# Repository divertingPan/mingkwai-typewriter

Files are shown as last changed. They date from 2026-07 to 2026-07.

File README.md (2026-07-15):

# Chinese Mingkwai Typewriter/明快打字机（中文打字机）

[][cc-by-nc]

本项目使用CC BY-NC 4.0进行许可。This work is licensed under a
[Creative Commons Attribution-NonCommercial 4.0 International License][cc-by-nc].[][cc-by-nc]

[cc-by-nc]: https://creativecommons.org/licenses/by-nc/4.0/
[cc-by-nc-image]: https://licensebuttons.net/l/by-nc/4.0/88x31.png
[cc-by-nc-shield]: https://img.shields.io/badge/License-CC%20BY--NC%204.0-lightgrey.svg

这是一个开源项目，欢迎DIYer在此基础上转载/改进/魔改，但请标注来源。禁止盗用、未授权的商用。

## 1. 背景

这是一个我的个人项目，我试图用现代科技来低成本的复现明快打字机，因此不拘泥于纯机械的执念，我的目标是先快速将他运行。

另外，低成本的实现也能帮助更多人自己做或者研究这个东西。

---

## 2. 文件详情

### 字表与字体

所有文件的基础来自于网站[https://mingkwai.atelier-anchor.com/](https://mingkwai.atelier-anchor.com/)

但此网站目前（截至2026年7月3日）暂时更新不可见。

- 项目中展示的字模图样、编码示意图、字体设计等，其原版权归属于原设计团队，本项目仅用于验证机械结构寻址和动作的测试展示，实物仅用于个人研究，绝不用于任何商业用途。

### 带v0.x.x版本号的文件夹

齿轮组与字轴滚筒的联动设计。目前仅有用来模拟运动测试用的最基本模型。后续需要完善装配细节，以及与纸打字的部分的联动。

---

## 3. 成本记录

| 材料\工艺 | 价格 (￥) |
| --- | --- |
| Arduino mega2560（后期开发尽可能兼容uno以再省点成本） | ≈60（祖国版） |
| USB Host Shield* | 19.2 |
| USB有线薄膜键盘 | 9.9 |
| 键盘轴和键帽 | |
| 柔性树脂印版 | 约100一张（A4幅面） |
| 电磁离合器 | |
| 42步进电机（长23） | |
| 闭环驱动 | （可能没必要，且贵） |
| 同步带/轮 | |
| 齿轮通用件 | |
| 3D打印部件耗材+工费（倘若你没有3D打印机） | |
| 治具成本 | |
| 所需工具 | |
| Todo | |

*USB Host Shield的库文件：[felis/USB_Host_Shield_2.0: Revision 2.0 of USB Host Library for Arduino.](https://github.com/felis/USB_Host_Shield_2.0) 

---

## 4. 进度

### （update 20260711）**结构测试_v0.3.1**:

鉴于同步带计算传动比简单很多，因此着重设计了B-roll的结构，使用了多级皮带轮，需要实际做一下，测试精度和稳定性，曾想过把预览轴用屏幕取代，但是感觉会使原机械风味丧失大半，所以还是保留。

【A-roll：最大的转盘，B-roll：二级转盘，C-roll：八面轴，view-roll：预览轴】

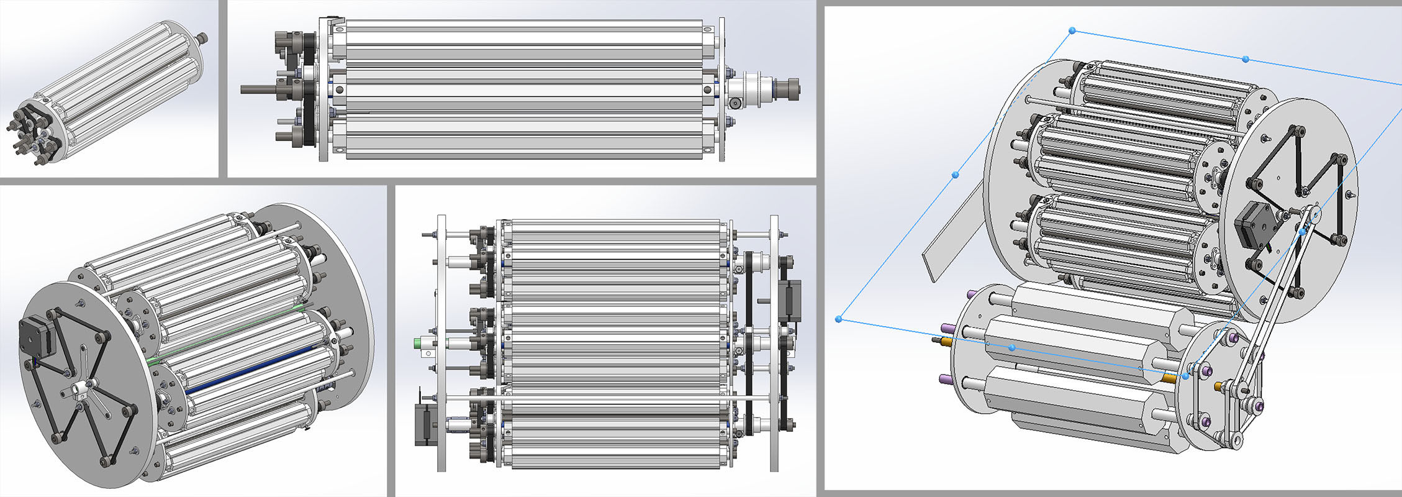
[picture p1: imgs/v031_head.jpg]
v031 preview


打样了印版，对比测试了两种厚度的柔性树脂印版，肉眼观察树脂印版精度效果极佳，但风险是时间久会变硬，对于盖章的影响目前未知。

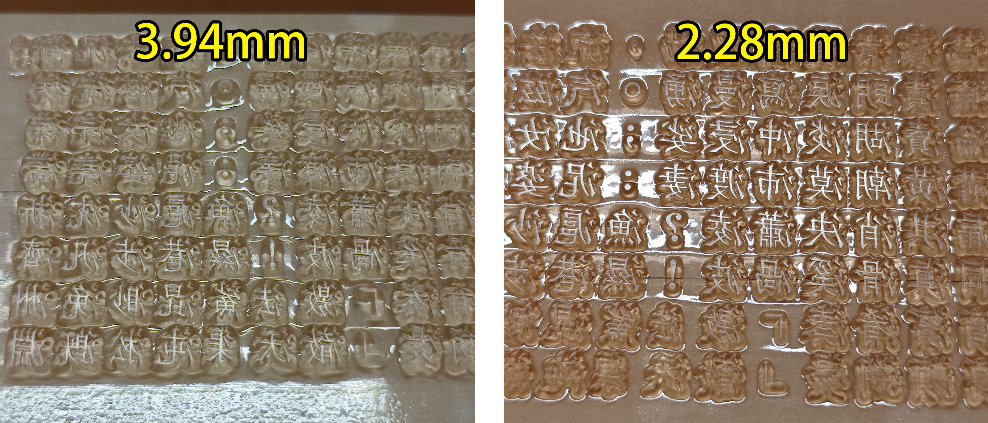
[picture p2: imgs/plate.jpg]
sample of the plate


下面展示的是使用印版沾取7021印油盖印的效果，左侧是轻轻施压，右侧是重压，（靠左的文字是薄印版，靠右的字是厚印版，不特别大力压的话，实际效果差别不大，可以哪个便宜做哪个）可以看出柔性印版对压力的要求没有那么高，在指定字上沾墨，轻轻压向纸面即可。
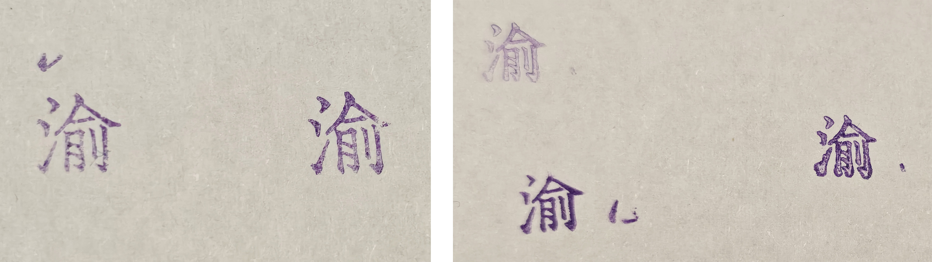
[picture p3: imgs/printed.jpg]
testing the characters


激光雕刻的胶皮不如柔性印版的效果好，盖印时我试了几次都没能完美盖出清晰的字迹。且二者加工成本接近，但是如果提升雕刻精度则会提升工费，且提升效果未知，整体性价比个人认为柔性印版最佳

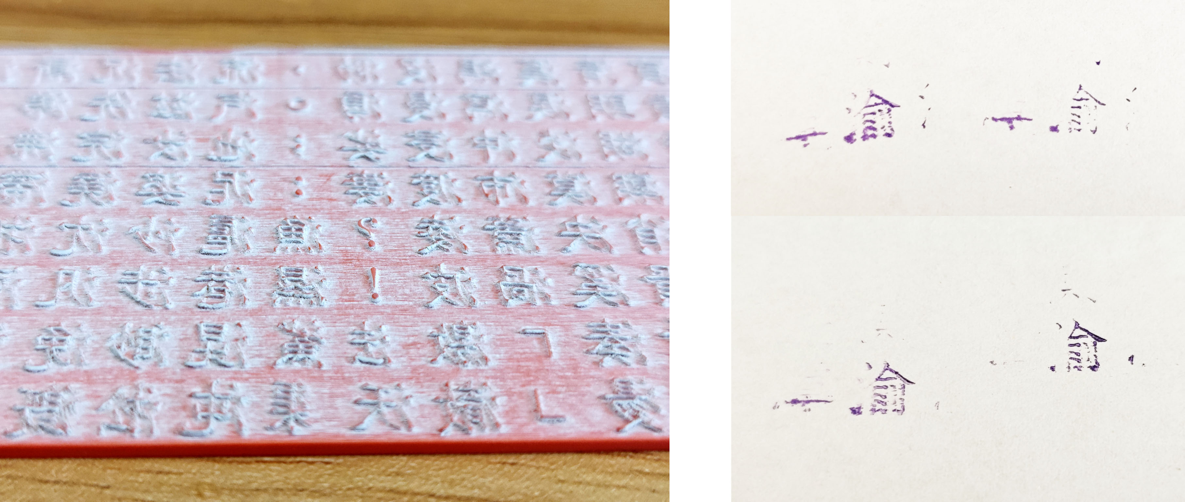
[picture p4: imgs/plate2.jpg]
rubber plate test


### （update 20260703）**结构测试_v0.3.0**:

重构了转轴部分的转盘传动，使用同步带驱动，大幅简化了运动和构造。v0.2.2完全不合理，直接废弃不用看了。

之后的版本需要将设计重心放在电机与轴的配合，代码，如何将字打在纸上（可能会参考回墨戳的设计，鉴于我想要通过橡皮印章方法刻字）

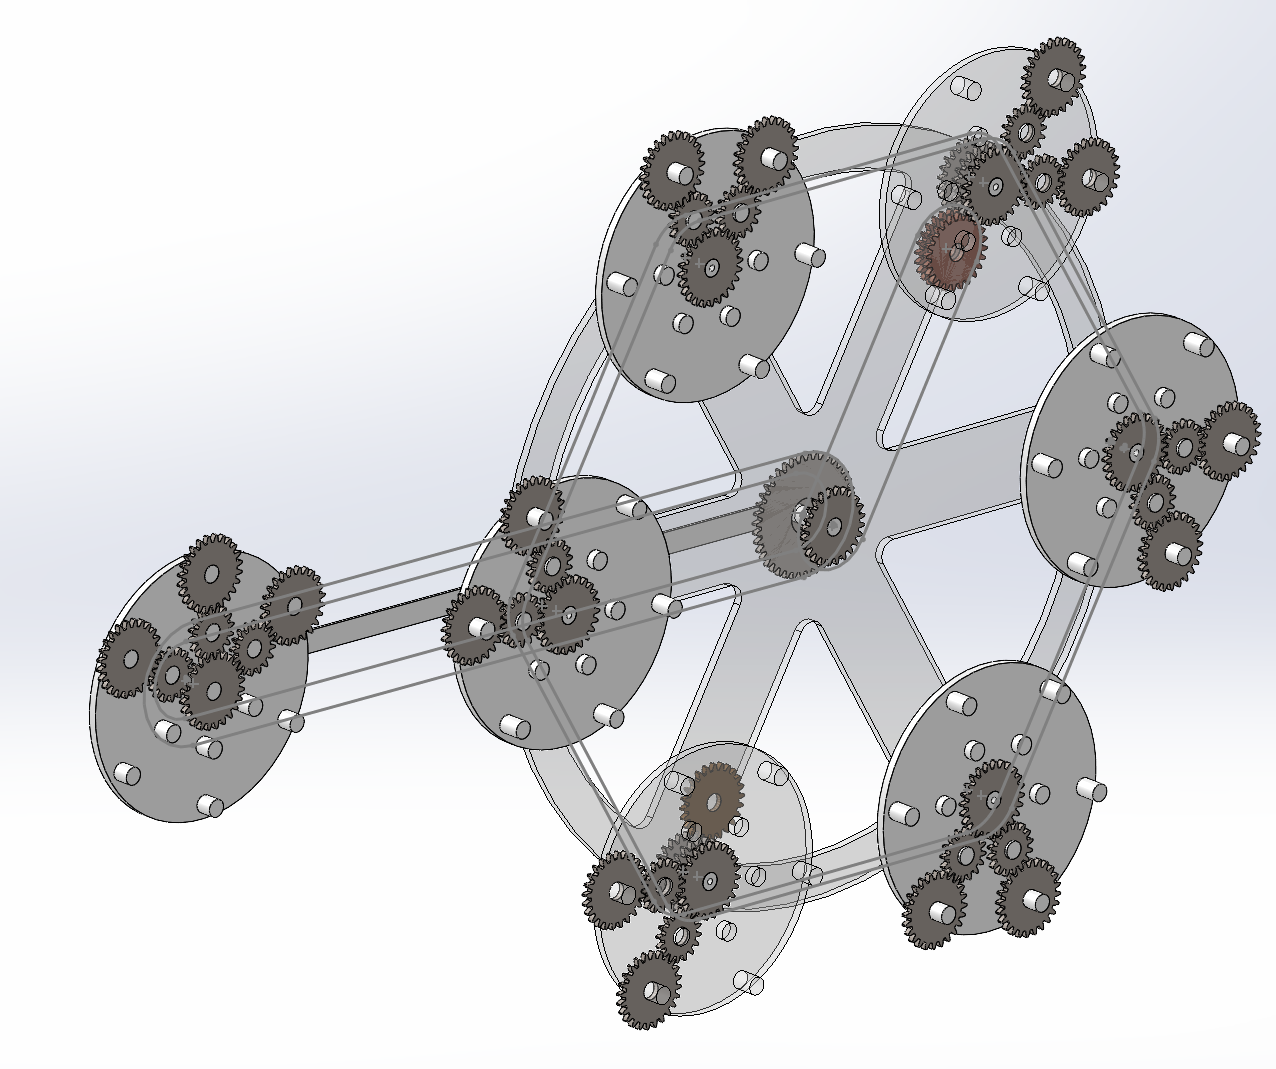
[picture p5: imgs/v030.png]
v0.3.0 testing model


---

### （update 20250424）**结构测试_v0.2.2 (for 3Dprint)：**

将转筒的齿轮编码部分用3D打印制作了一下，用于实际测试装配、尺寸、运动、误差等情况。文件内有这些模型的sw文件（主文件为“大筒装配体”）和stl文件。可直接打印，前缀为所需数量。装配与演示情况见视频：[【开源计划】低成本明快打字机设计方案第二期_哔哩哔哩_bilibili](https://www.bilibili.com/video/BV1TwLZzwEFX/)

文字滚筒也测试了带拔模角度（1mm, 30°）的3D打印模型，能很好的解决小字体下破损的问题。但这种模型的建模目前还未找到很好的办法制作。这个测试模型是用solidworks的拔模功能手调微操做出来的，特别麻烦，无法扩展到大的正式版制作。

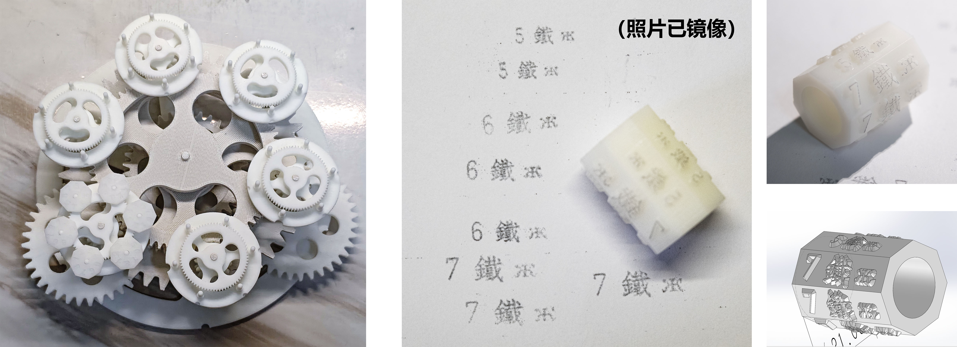
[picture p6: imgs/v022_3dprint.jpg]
v022 3dprint model


---

### （update 20250401）

光固化树脂打样了一个带字的字轴，如下图，文字凸起均为1mm，数字是字体的高度，单位mm。6mm及以下的字号可能会出现细线缺失的问题。而即使是8mm的大字，点或细线部分，我用手去扣动，感觉牢固性也堪忧。目前在寻找学习如何制作一个下大上小的那种锥形刻面文字的建模效果。solidworks做这种模型无力，得换工具了。

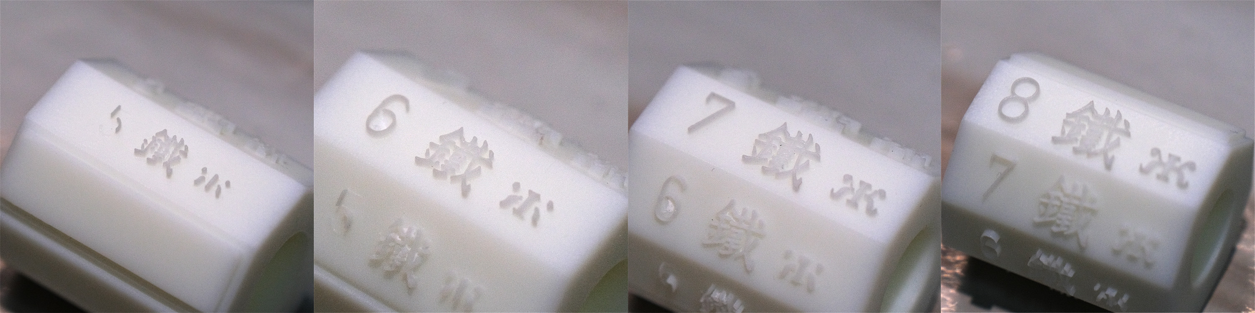
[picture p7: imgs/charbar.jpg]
characters testing


---

### （update 20250319）

稍微精细的建模了转轮组比较重要的运动部分，以便打样测试运动。这部分的sw模型已上传（结构测试_v0.2.1），并且附带有齿轮运动配合关系。

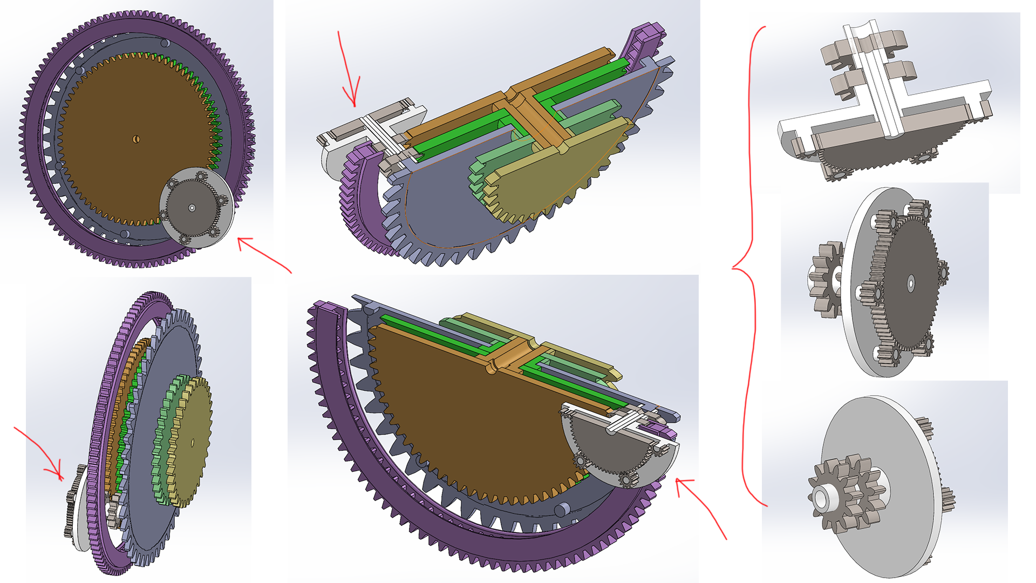
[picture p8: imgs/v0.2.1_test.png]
v0.2.1 testing model


todo：

- 测试当前尺寸下文字雕刻出的效果以及配合墨带印字的清晰度。以便最终确定核心机构的尺寸

- 实际验证没问题后，加上轴承，并且优化解耦出的三个齿轮的动力传动。

---

### （update 20250316）

紧凑的新结构初步验证完毕，可单独控制三个红齿轮的角度，从而完全将运动独立出来，如上图所示。带有预览轴的联动部分以及结构细节以后做。（结构测试_v0.2.0）

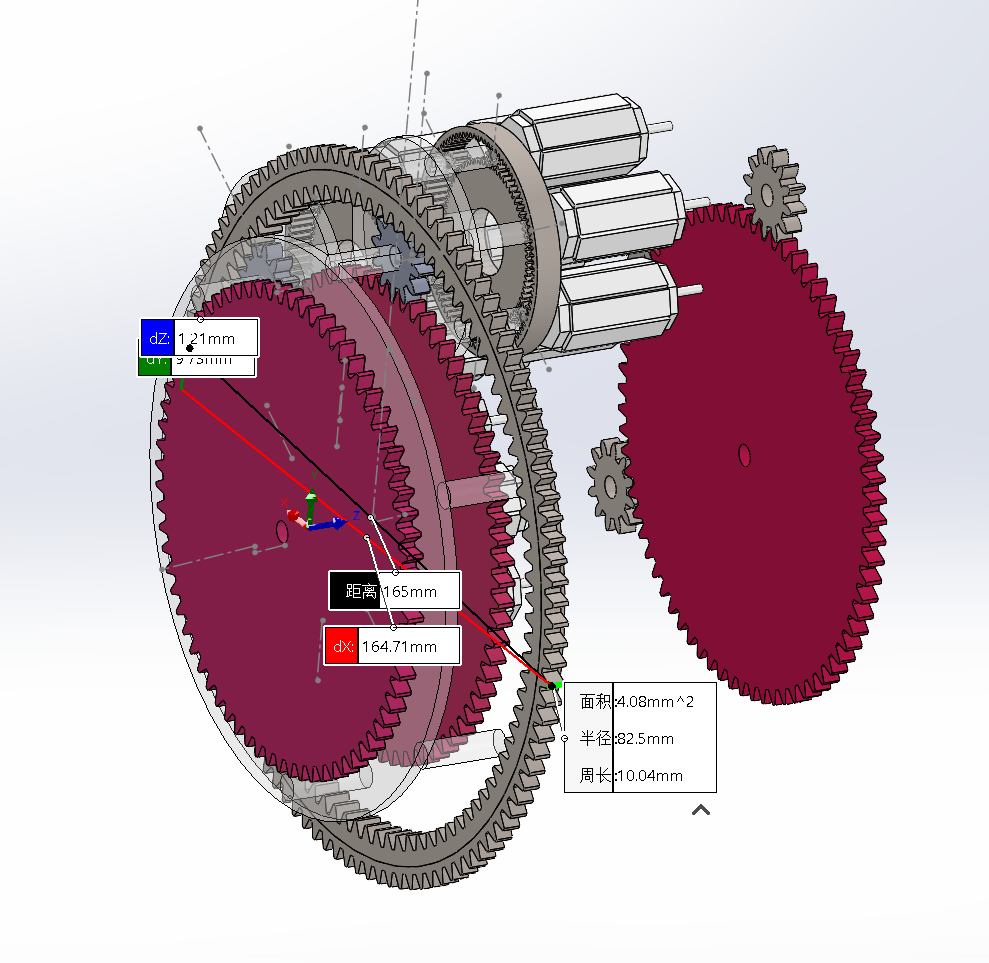
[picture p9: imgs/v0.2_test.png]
v0.2 testing model


---

（update）简单设想了一个更紧凑的方案，理论上应该兼容机械编码，实际参数和设计还未验证。

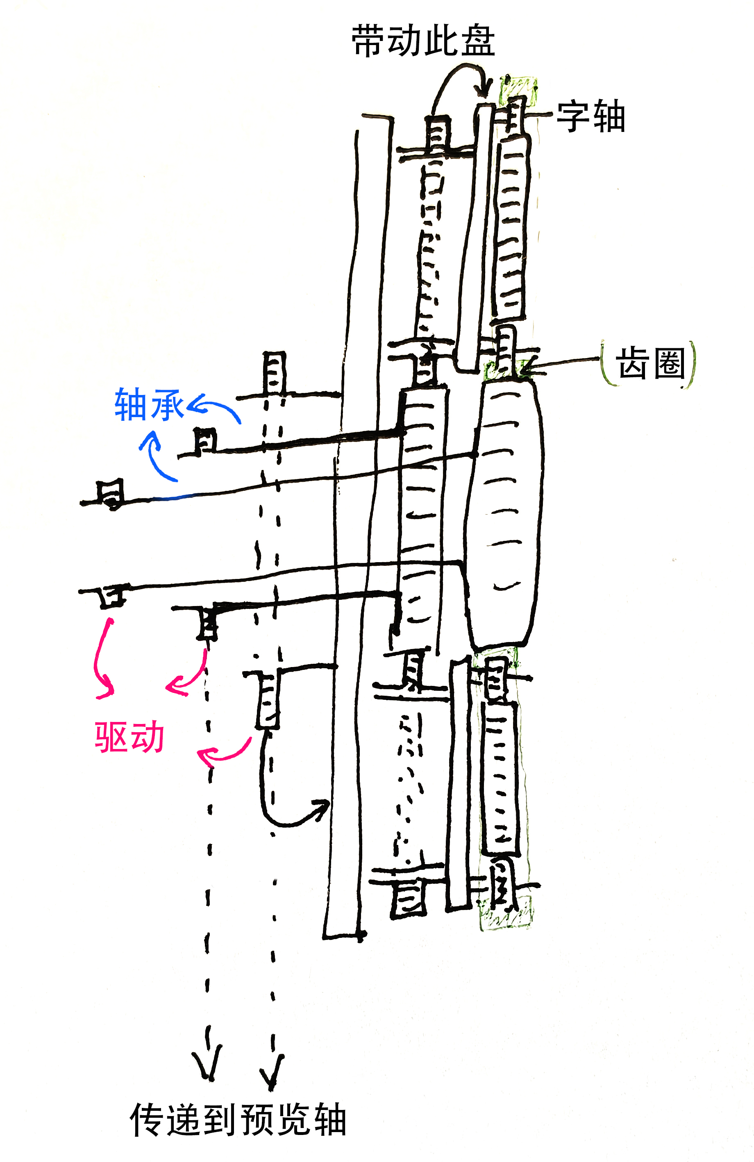
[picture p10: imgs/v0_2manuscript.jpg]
v0.2 manuscript design


---

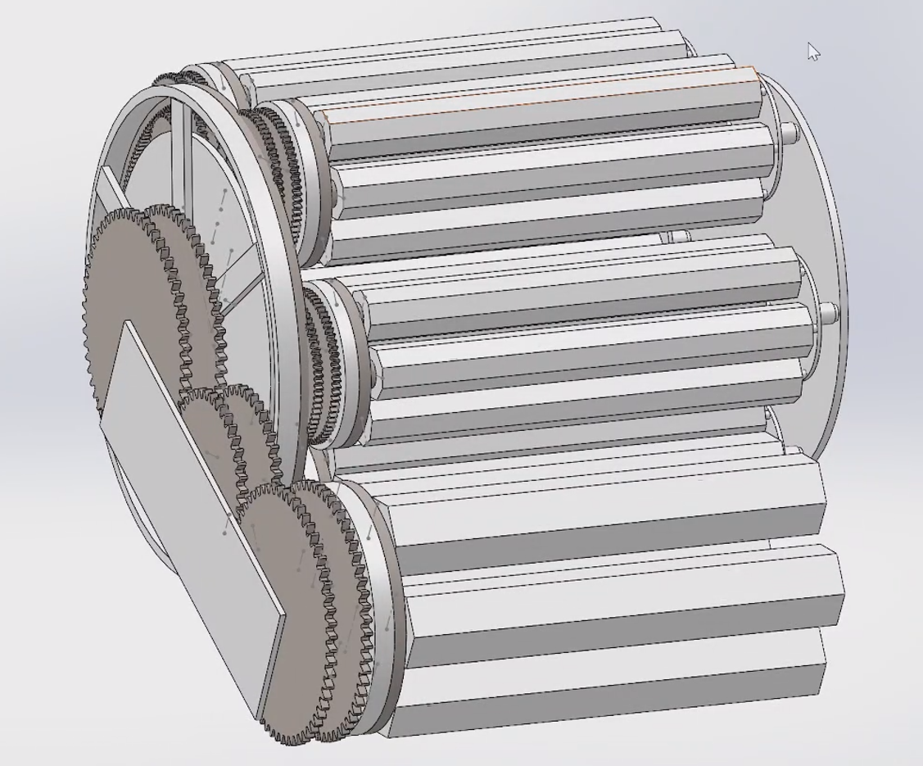
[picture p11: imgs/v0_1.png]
v0.1 design


目前设计了3组齿轮独立检索字的结构，齿轮的控制初步设计使用电机控制角度以此检索对应文字的轴。（字模滚筒_v0.1）

下一步先以此结构打样出关键配件，齿轮如有通用件则直接买成品。主要任务是对齿轮部分进行运动验证。

按理说，“电机控制角度”也可以用什么机械结构来实现，但我实在搞不懂。

【我所理解的原始专利对最细轴的控制方法，是用一个类似牙刷样的齿轮齿条去拨动，但是个人感觉那样太不可靠了，干脆都用同样设计思路迭代三层的齿轮为妙。】

机架设计，进纸机构等还没做。

电控的部分也还没弄。

---

**目前问题：**

1. 运动配合部分有点乱，而且模拟运动起来非常卡顿。齿轮的轴固定和轴承的部分也没有专门设计。要结合实际打样再做。

2. 最大的主轮的电机没有把模型放进去，实际的主机架和最左侧齿轮之间还需要一个电机。后期要重构这个机芯的模型。

**（update）关于机械编码实现的设想：**

1. 参考琴键开关的结构，可以实现纯机械的按钮位置编码，配合带位置编码的圆盘和弹簧，利用前文设计的多层嵌套。也许能够实现完全纯机械的结构。但是直觉会很复杂的结构，材料强度和按压的力度也不知道能否在可接受范围内。需要打样测试。（下图草稿）

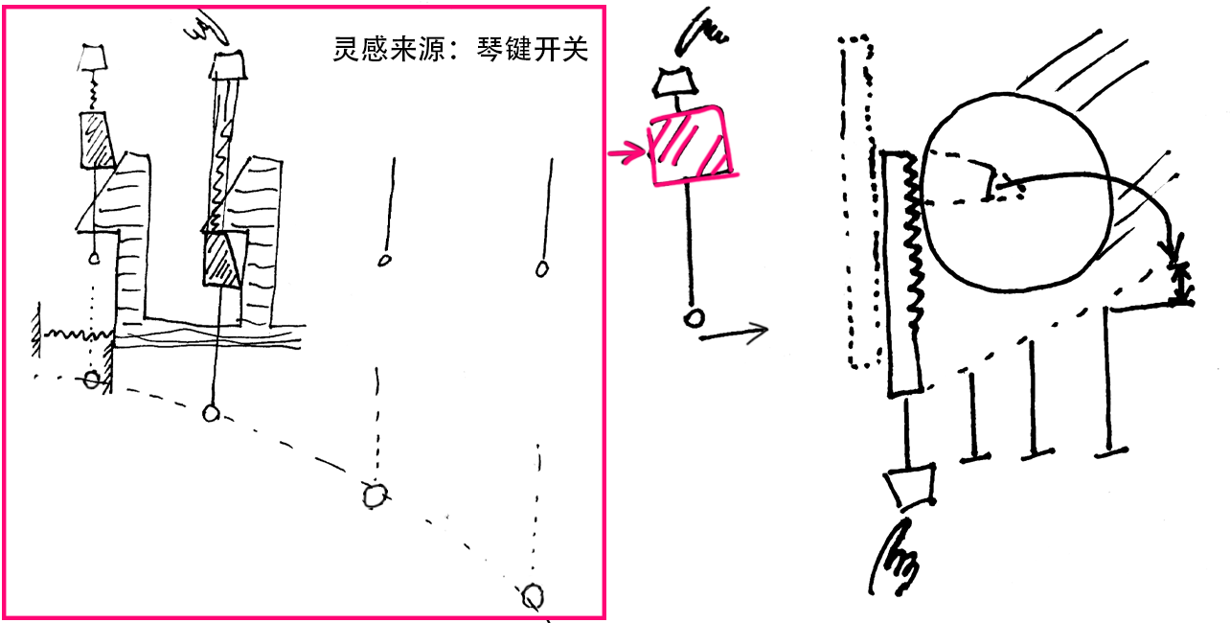
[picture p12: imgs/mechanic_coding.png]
mechanic encoder


2. 在初代专利图中存在一个阶梯盘，猜测可根据阶梯实现位置定位。尚没有研究具体如何配合运动？一种可能是通过正反转来归位，
   键盘控制一个卡扣的位置使得滚筒卡在特定阶梯上。另一个问题在于如何做成3级嵌套？以及具体正反转的实现？（目前看可行性不如1）

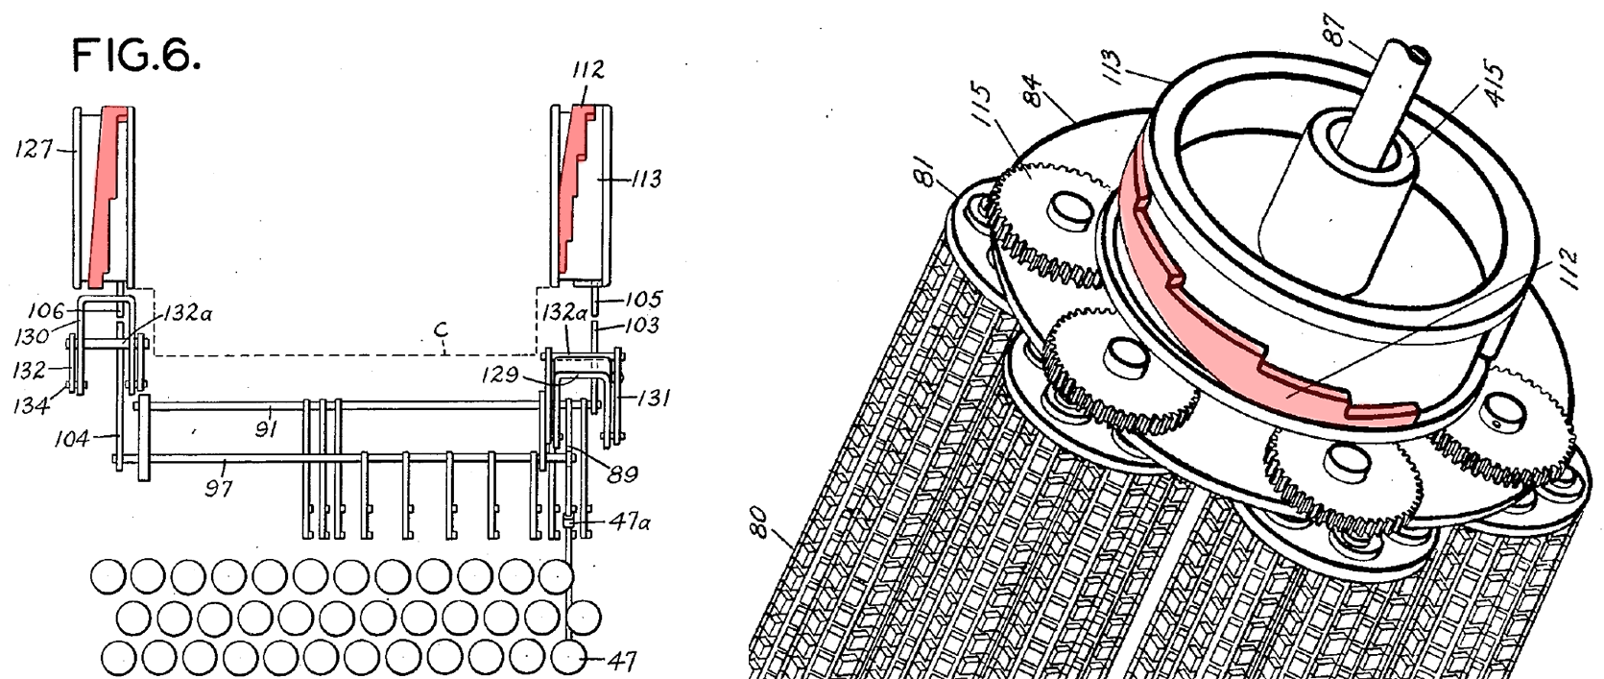
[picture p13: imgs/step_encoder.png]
step encoder


##

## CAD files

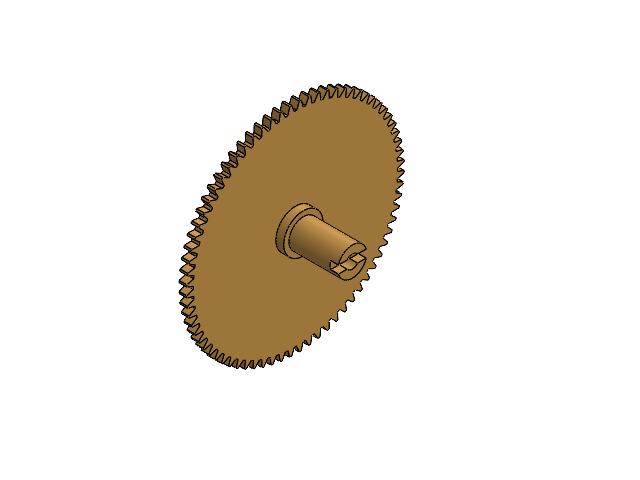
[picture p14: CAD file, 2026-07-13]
结构测试_v0.2.2 (for 3Dprint)/中转筒自转驱动齿轮大端.SLDASM
spur gear_gb
零件4

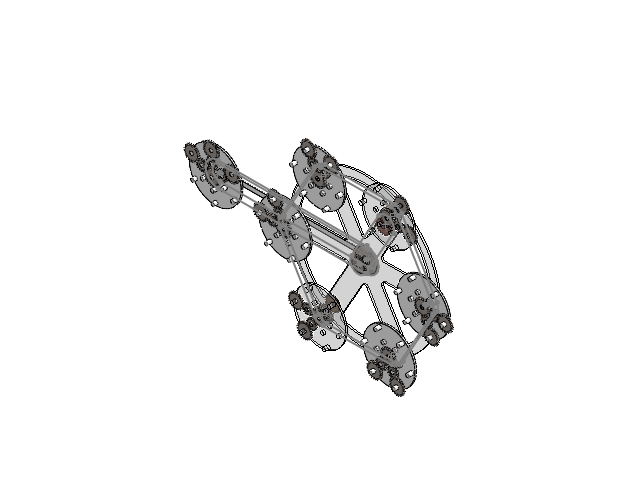
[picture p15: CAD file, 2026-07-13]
结构测试_v0.3.0/装配体_rolls_head.SLDASM
rolls机架
P-roll支架
spur gear_gb x 57
零件_Proll_center_gear_axis
A-roll支架
B-roll支架 x 6
零件_Broll_center_gear_axis x 6
零件_Aroll_center_gear_axis

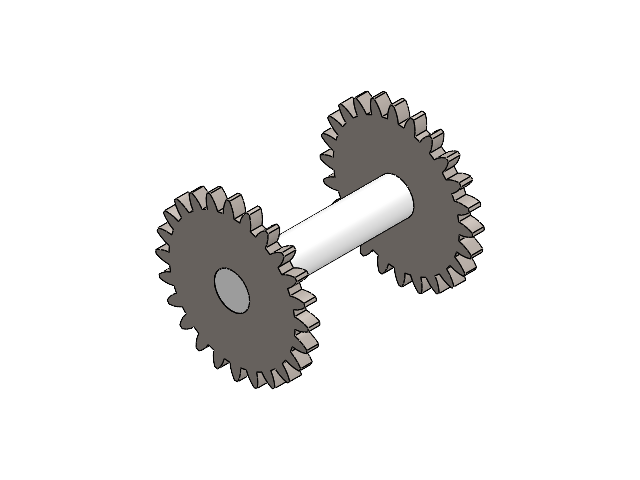
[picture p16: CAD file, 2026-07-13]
结构测试_v0.3.0/装配体_Aroll_center_gear.SLDASM
零件_Aroll_center_gear_axis
spur gear_gb x 2

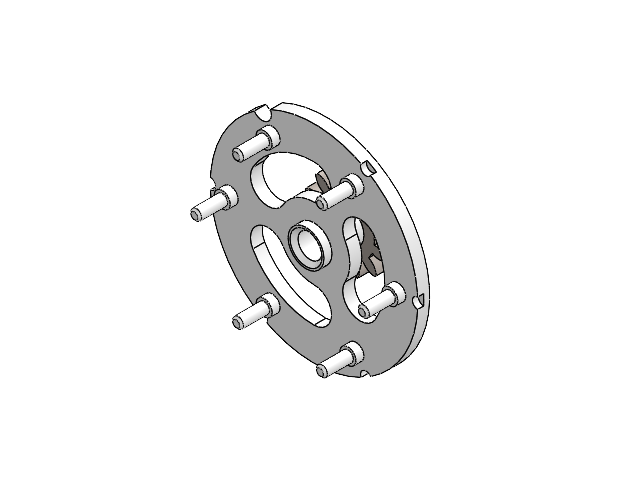
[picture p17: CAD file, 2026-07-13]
结构测试_v0.2.2 (for 3Dprint)/中转盘盘体.SLDASM
2级滚轴齿轮支架
spur gear_gb

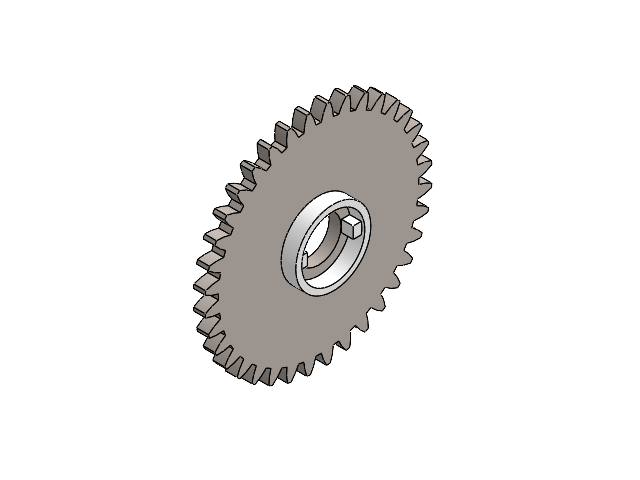
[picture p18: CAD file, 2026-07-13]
结构测试_v0.2.2 (for 3Dprint)/小转筒自转驱动齿轮小端.SLDASM
spur gear_gb
零件6

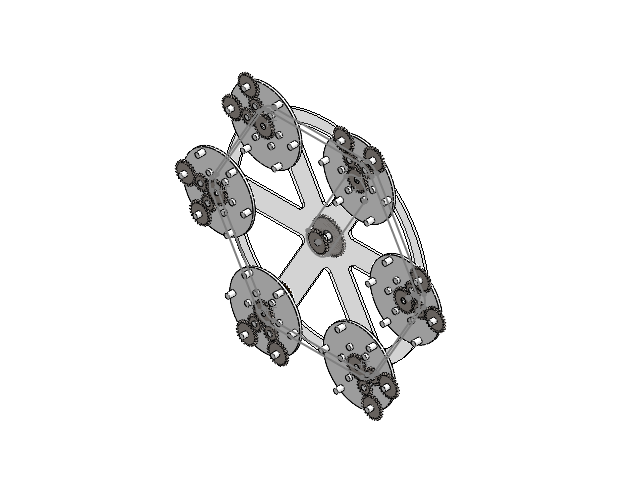
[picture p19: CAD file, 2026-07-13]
结构测试_v0.3.0/装配体_Aroll.SLDASM
A-roll支架
B-roll支架 x 6
spur gear_gb x 48
零件_Broll_center_gear_axis x 6
零件_Aroll_center_gear_axis

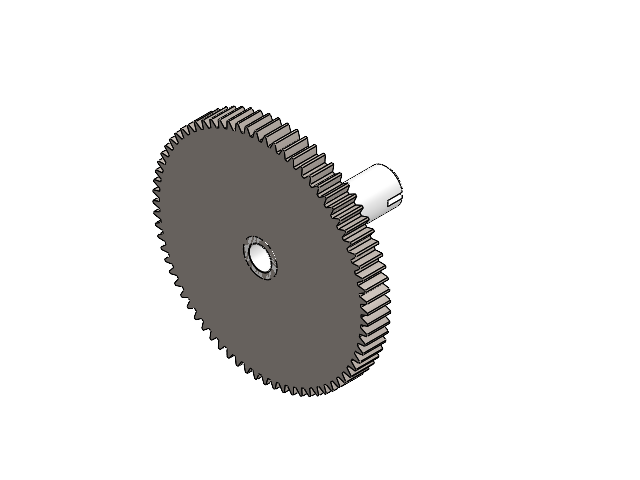
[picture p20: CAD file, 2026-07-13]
结构测试_v0.2.2 (for 3Dprint)/小轴动力齿轮大端.SLDASM
spur gear_gb
零件1

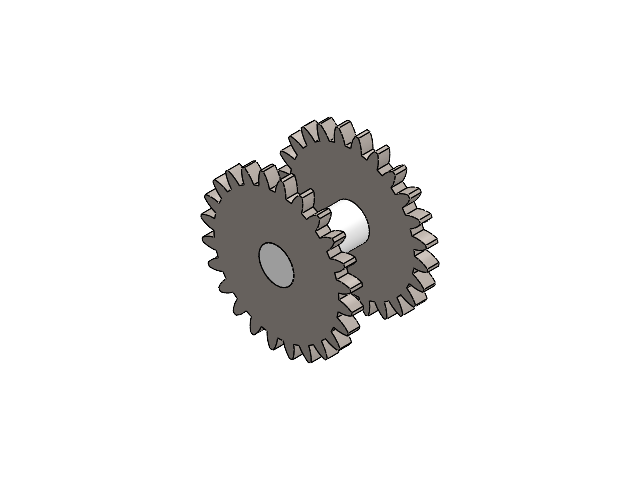
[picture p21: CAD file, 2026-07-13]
结构测试_v0.3.0/装配体_Proll_center_gear.SLDASM
零件_Proll_center_gear_axis
spur gear_gb x 2

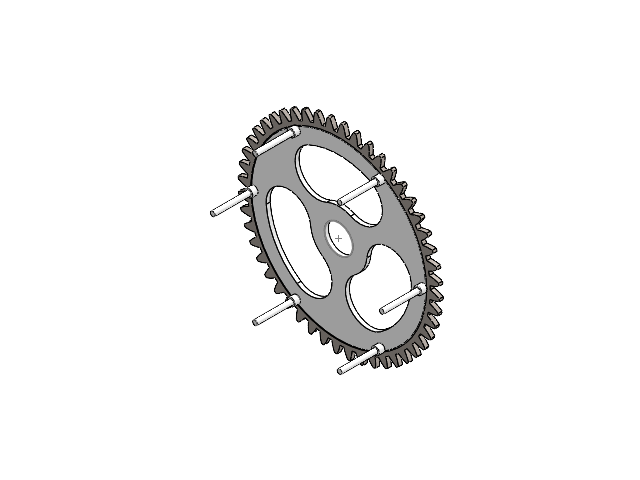
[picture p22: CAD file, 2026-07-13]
结构测试_v0.2.2 (for 3Dprint)/大转筒的齿轮架.SLDASM
1级滚轴齿轮支架
spur gear_gb

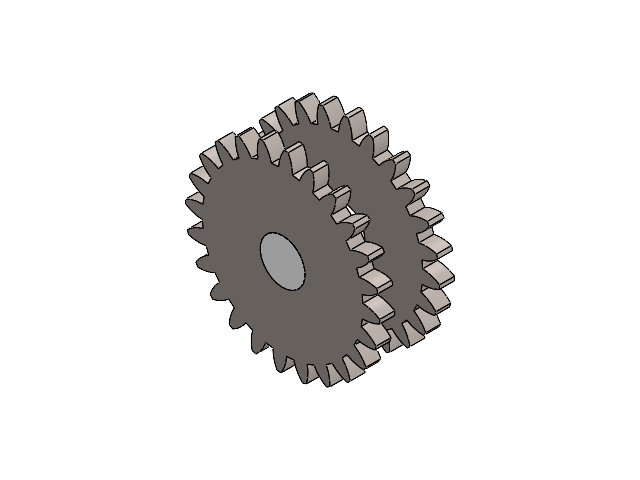
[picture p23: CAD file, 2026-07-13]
结构测试_v0.3.0/装配体_Broll_center_gear.SLDASM
零件_Broll_center_gear_axis
spur gear_gb x 2

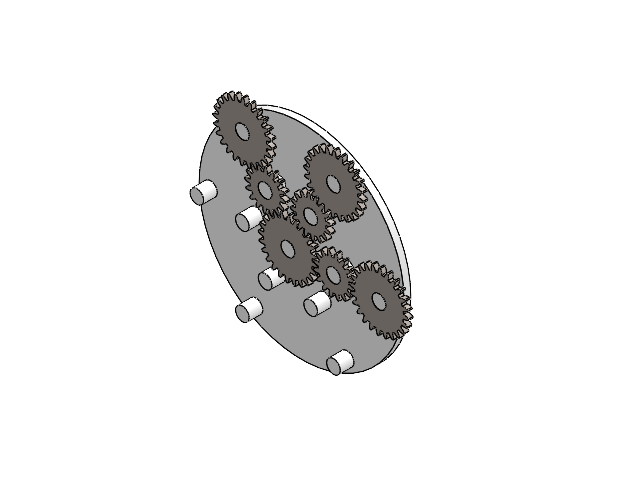
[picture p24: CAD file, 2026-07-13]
结构测试_v0.3.0/装配体_Proll.SLDASM
P-roll支架
spur gear_gb x 9
零件_Proll_center_gear_axis

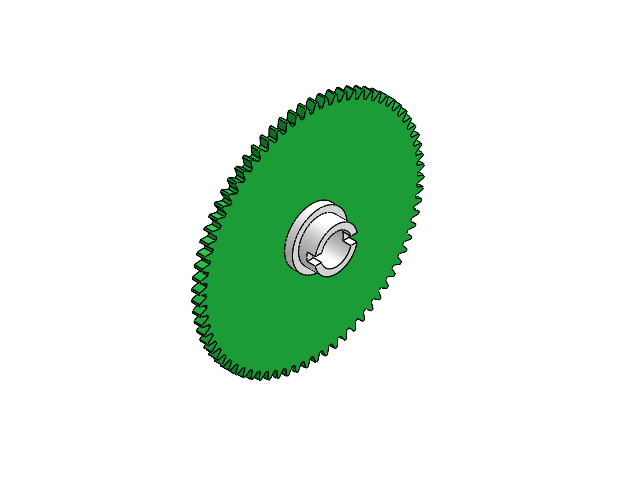
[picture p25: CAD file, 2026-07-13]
结构测试_v0.2.2 (for 3Dprint)/小转筒自转驱动齿轮大端.SLDASM
spur gear_gb
零件5

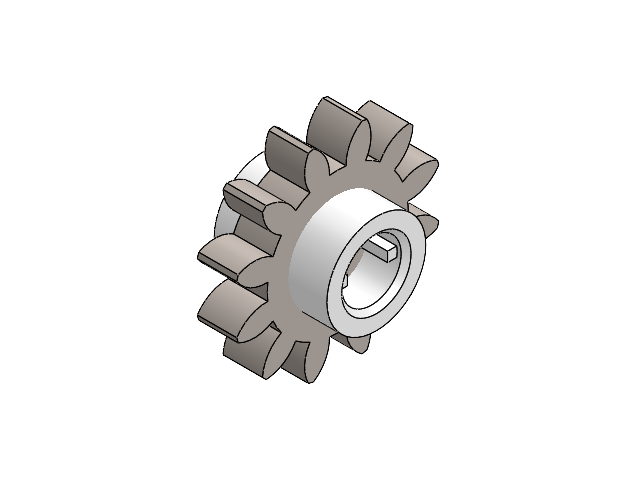
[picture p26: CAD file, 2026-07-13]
结构测试_v0.2.2 (for 3Dprint)/小轴动力齿轮小端.SLDASM
spur gear_gb
零件2

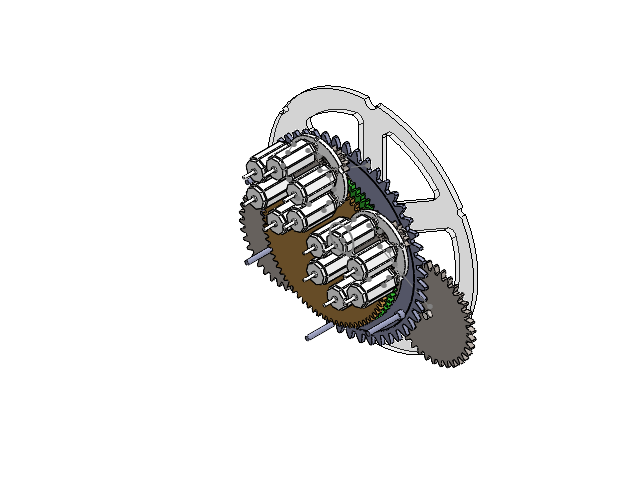
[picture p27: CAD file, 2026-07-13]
结构测试_v0.2.2 (for 3Dprint)/大筒装配体.SLDASM
1级滚轴齿轮支架
spur gear_gb x 25
零件4
零件5
零件6
零件7
支架
2级滚轴齿轮支架 x 2
八边形筒 x 12
零件1 x 2
零件2 x 2

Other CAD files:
结构测试_v0.2.2 (for 3Dprint)/小筒装配体.SLDASM
结构测试_v0.3.0/装配体_Broll.SLDASM
结构测试_v0.2.2 (for 3Dprint)/中筒联动外齿圈.SLDASM
结构测试_v0.2.2 (for 3Dprint)/中转筒自转驱动齿轮小端.SLDASM
结构测试_v0.1/1级滚筒大齿轮连接圈.SLDPRT
结构测试_v0.1/1级滚筒装配.SLDASM
结构测试_v0.1/1级滚筒连接件.SLDPRT
结构测试_v0.1/2级滚筒大齿轮连接圈.SLDPRT
结构测试_v0.1/2级滚筒装配.SLDASM
结构测试_v0.1/2级滚筒连接件.SLDPRT
结构测试_v0.1/3级滚筒装配.SLDASM
结构测试_v0.1/八边形筒.SLDPRT
结构测试_v0.1/大机架.SLDPRT
结构测试_v0.1/字芯总装配.SLDASM
结构测试_v0.1/模拟用电机模型.SLDPRT
结构测试_v0.1/预览六面滚筒.SLDPRT
结构测试_v0.1/预览滚筒大齿轮连接圈.SLDPRT
结构测试_v0.1/预览滚筒装配.SLDASM
结构测试_v0.1/预览滚筒连接盘.SLDPRT
结构测试_v0.1/预览齿轮轴装配.SLDASM
结构测试_v0.2.0/1级滚轴齿轮支架.SLDPRT
结构测试_v0.2.0/2级滚轴齿轮支架.SLDPRT
结构测试_v0.2.0/中筒装配体.SLDASM
结构测试_v0.2.0/八边形筒.SLDPRT
结构测试_v0.2.0/大筒装配体.SLDASM
结构测试_v0.2.0/小筒装配体.SLDASM
结构测试_v0.2.1/1级滚轴齿轮支架.SLDPRT
结构测试_v0.2.1/2级滚轴齿轮支架.SLDPRT
结构测试_v0.2.1/中筒装配体.SLDASM
结构测试_v0.2.1/中转盘盘体.SLDASM
结构测试_v0.2.1/中转筒自转驱动齿轮大端.SLDASM
结构测试_v0.2.1/中转筒自转驱动齿轮小端.SLDASM
结构测试_v0.2.1/八边形筒.SLDPRT
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
